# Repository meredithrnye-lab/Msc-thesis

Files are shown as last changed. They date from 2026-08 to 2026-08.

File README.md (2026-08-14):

# Design and Manufacturing Feasibility Assessment of a Hybrid Jamming Soft Robotic Finger Exoskeleton for Hand Rehabilitation
**This repository contains dissertation work completed in partial fulfillment of the requirements for the degree MSc Rehabilitation Engineering and Assistive Technologies of University College London**

[Dissertation Report](/Reports/Design%20and%20Manufacturing%20Feasibility%20Assessment%20of%20a%20Hybrid%20Jamming%20Soft%20Robotic%20Finger%20Exoskeleton%20for%20Hand%20Rehabilitation.pdf)
authored by [Meredith Nye](https://www.linkedin.com/in/meredith-nye-89455a1b5/), with advisors [Rui Loureiro](https://www.linkedin.com/in/rui-cv-loureiro/) and [Peter Kyberd](https://www.linkedin.com/in/peter-kyberd-b78b1757/)

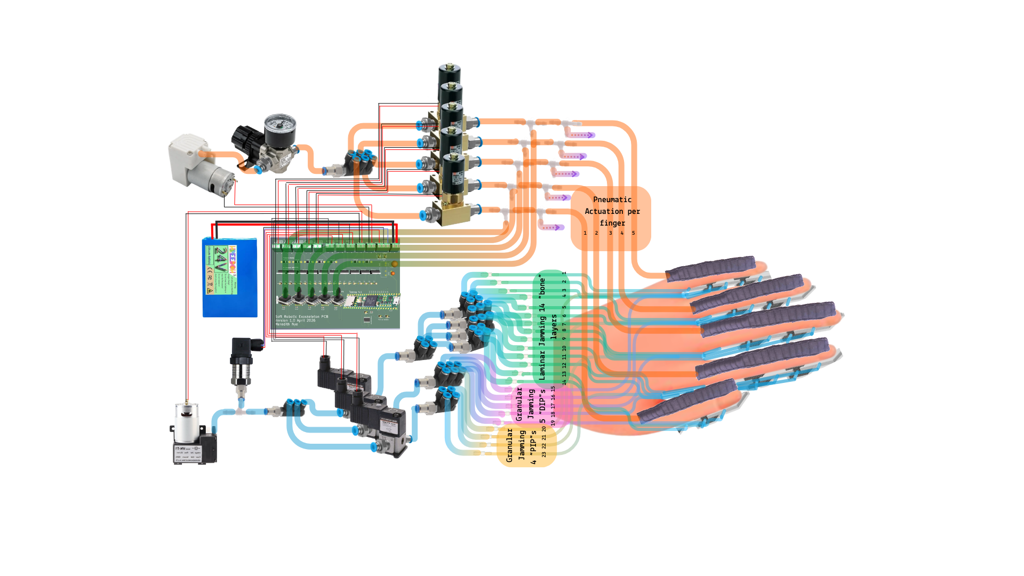
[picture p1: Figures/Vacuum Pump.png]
Full theoretical system design


## Abstract
#### Background and Aims 
Hand impairment 
following stroke, arthritis, and age-related conditions requires high-repetition rehabilitation
that soft robotic exoskeletons are well suited
to deliver. Jamming-based variable-stiffness
mechanisms are promising but underdeveloped, typically offering only single-family, binary stiffness control. This project aimed to
evaluate the design and manufacturing feasibility of a hybrid granular–laminar jamming
soft robotic finger exoskeleton, hypothesising
that hybrid jamming could be integrated into
a compact finger architecture without compromising manufacturability.

#### Methods 
Sixteen design specifications were synthesised from hand exoskeleton literature.
A finger-level prototype was partially built
comprising a fabric pneumatic actuator over
a silicone hybrid jamming module (adapted
from an existing H-block design), with custom PCB control. Actuators were manually
inflated; the jamming module was cast across
four silicone iterations. Each specification was
rated on design and manufacturing axes and
combined into an overall feasibility rating.

#### Results 
The jamming geometry was rated Feasible on the design axis, but all
four casting iterations showed persistent tackiness and incomplete curing at fine layer-pocket
features, so no complete module
was assembled. Fabric actuators inflated with
one demonstrating bending but did not reach
target flexion pressure. No inferential statistics
were applied; findings rest on single-prototype
demonstration and inspection evidence.

#### Summary and Conclusions 
The hybrid jamming specification was rated Not Feasible
overall, only partially supporting the hypothesis. Fine mold geometry and fabrication constraints, not conceptual incompatibility, prevented reliable manufacture. Hybrid jamming
remains a credible route to graduated-stiffness
rehabilitation exoskeletons, but reliable small scale silicone manufacturing must be resolved
before clinical translation.

## Relevant Repository Files
[PCB Gerber Files](/PCB%20Design/Gerbers.zip)

Version 3 Mold Files: [I3_RHM](/Manufacturing/V3_RM.stl), [I3_RHF](/Manufacturing/V3_RF.stl), [I3_LHM](/Manufacturing/V3_LM.stl), [I3_LHF](/Manufacturing/V3_LF.stl)

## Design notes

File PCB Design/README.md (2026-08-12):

# PCB Design
The custom PCB design is made to accommodate all the electronics needed for a
full glove system and uses a Teensy 4.1 micro-controller. It was manufactured by JLCPCB using an FR-4 substrate. 
Components were manually soldered to the board, with the 0805 surface-mount capacitors and TSSOP multiplexer soldered using a reflow process. 

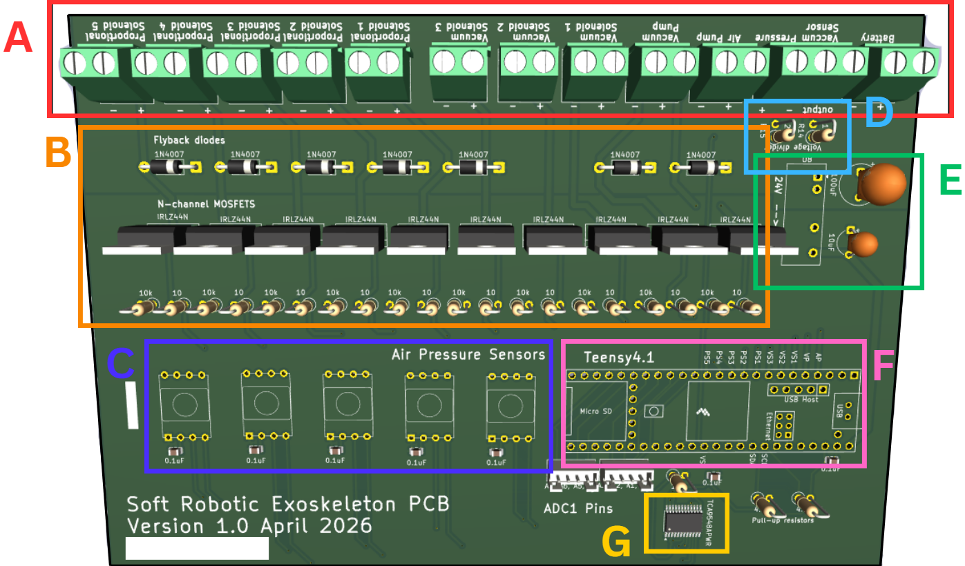
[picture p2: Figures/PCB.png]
PCB


This folder contains the KiCad files and gerber files associated with the first iteration of the PCB design.

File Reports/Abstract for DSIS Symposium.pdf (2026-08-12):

This project investigates a novel soft robotic exoskeleton design to enhance hand function in

individuals dealing with hand or finger muscle weakness. With a combined soft-fabric pneumatic

actuator and a bio-inspired granular-and-laminar jamming module, the soft exoskeleton aims to

achieve a biomimetic range of motion by varying the pneumatic actuator's air pressure across 8

distinct jamming configurations, with a similar or greater degree of stiffness modulation

compared to other designs. The pneumatic flexion will be achieved with an impulse-sealed air

pocket inside a pleated fabric pocket with stiff fabric lining the bottom layer, and elastic fabric

forming the top pleats. The jamming module will be silicone-molded following an H-block

design, in which rounded granular pockets serve as joints, and long laminar layers act as bones

slotted into the pockets to optimize load distribution along the exoskeleton's length. The study

will assess the feasibility of this design as a wearable exoskeleton, including overall device

weight, ROM, actuation speed, stiffness enhancement, and maximum force output, with and

without the jamming module. The aim is to contribute data on the viability and limits of jamming

mechanisms for enhancing soft robotic exoskeletons, as well as to provide insight into different

control methods that could optimize cost, computation speed, and functionality for soft robotic

exoskeletons.

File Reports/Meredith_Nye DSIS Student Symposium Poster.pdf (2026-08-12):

# Design and Evaluation of a Soft Exoskeleton Glove with Hybrid Jamming for Hand Rehabilitation

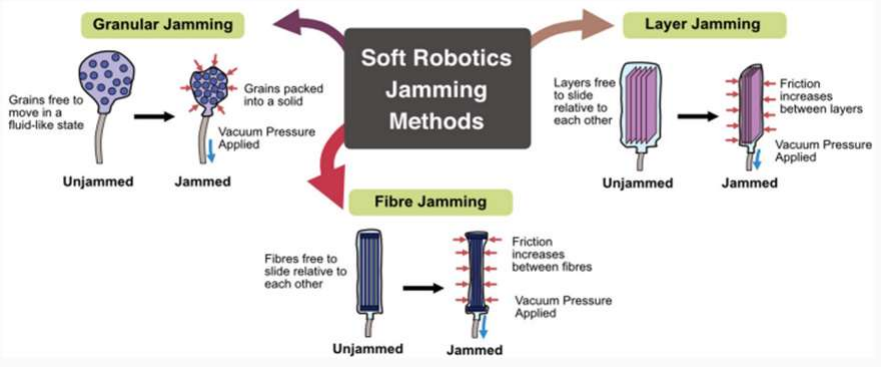
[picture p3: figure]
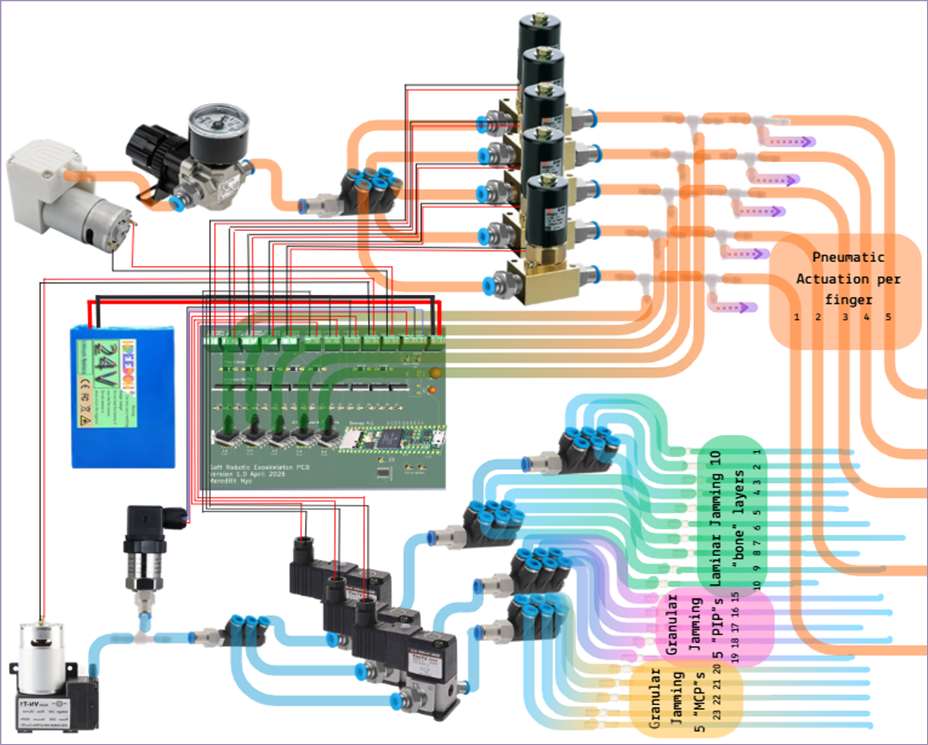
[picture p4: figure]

PRESENTER:
Program
Team
Supervisors

DSIS Student Research
Symposium 2026
PGT - 10

MSc Rehabilitation Eng. and Assistive Tech STARS Research Group
Rui Loureiro, Peter Kyberd

### Meredith Nye

Division of Surgery and Interventional Science, University College London

Figure adapted from: Liow L, Howard D. Jellyphant: A Soft, Elephant Trunk-Inspired Robotic Arm That Can Grab Objects. Frontiers for Young Minds. 2024.

# Background

Hand weakness resulting from neurological and musculoskeletal conditions can significantly impair daily function and quality of life. Effective rehabilitation often requires repetitive, progressive, and task-specific movement training with adaptable assistance (Reinkensmeyer et al., 2004). Soft robotic exoskeleton gloves have emerged as promising rehabilitation devices due to their flexibility, safety, and ability to support natural hand movement (Rus and Tolley, 2015). Jamming, shown below, is a technique used in soft robotics to provide controllable and reversible stiffness, allowing systems to remain flexible during movement while becoming rigid when additional support or stability is required.

# Aims

Aim:
To design and develop a bio-inspired soft exoskeleton glove incorporating hybrid jamming (granular and laminar) to provide adjustable, graduated support for hand rehabilitation. Research Questions:

### 1. Can a hybrid jamming structure provide

controllable and reversible stiffness and ROM suitable for assisting hand rehabilitation movements?

### 2. How does the design meet hand

rehabilitation requirements as determined from the literature?

### 3. How does the design compare quantitatively to

other designs in the research and on the market?

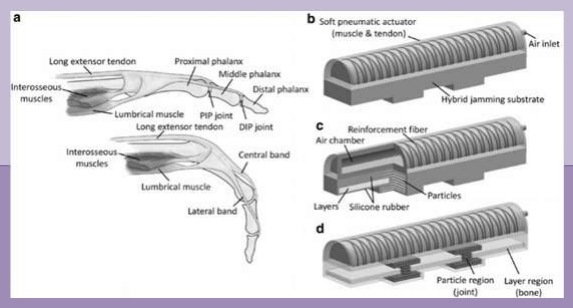
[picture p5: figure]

# Proposed Methodology

Testing will involve measuring force output and stiffness modulation with and without jamming, alongside ROM, actuation speed during finger flexion and extension, and power consumption. The goal is to provide a comprehensive look at the feasibility of the final design for hand rehabilitation.
Manufacturing will entail soldering custom PCB components, sewing, resin printing silicone molds, silicone pouring, and pneumatic pipe system construction.

# Design Rationale

Hand rehabilitation requires repetitive, task-specific movement with adjustable assistance, sufficient range of motion, and patient-specific adaptability. Devices must also be lightweight and safe to minimise user fatigue and reduce risk during prolonged use. The current design is also heavily inspired by pleated textile actuators and the bioinspired design shown below adopted from (Yang et al., 2019).

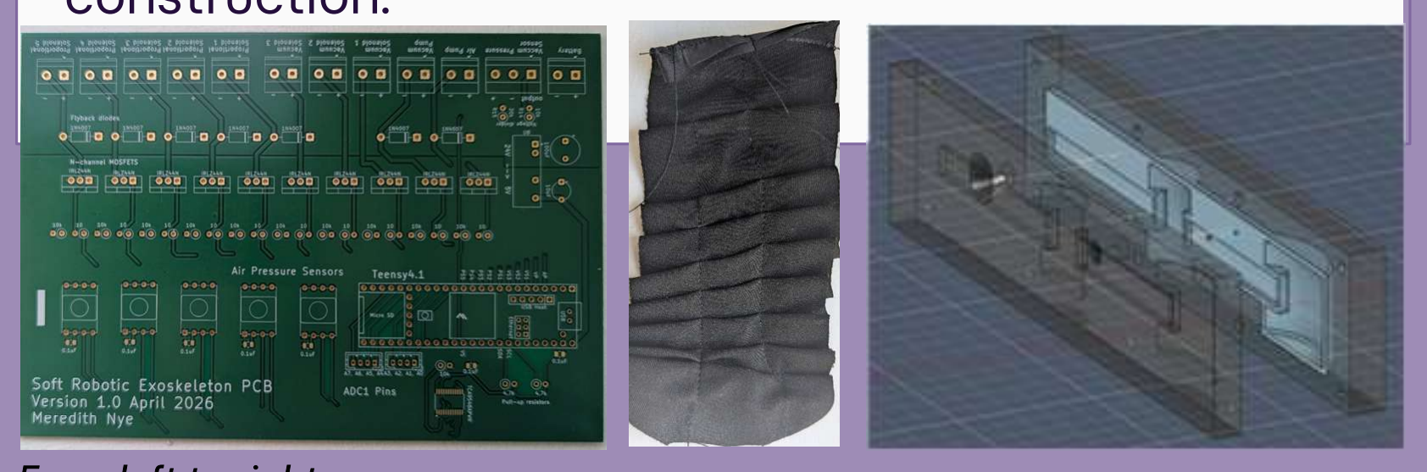
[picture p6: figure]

From left to right: Picture of the custom PCB board, hand-sewn fabric actuator mock-up, Fusion 360 model for the small half of the silicone finger’s resin mold A representation of the full glove design including battery, custom PCB with ground and power wirings, and tubing configurations where light blue tubes represent vacuum pressure and orange tubes represent air pressure.

Finger-level design of exoskeleton glove

The finger design has layered nylon fabric and mylar film for laminar jamming and EPS beads for granular jamming with oval silicone sections at the finger joints to improve fit and alignment targeting the higher load bearing joints as seen in the figure on the right.
A closed loop system will control the air pump-fabric actuator system, while the vacuum pump-jamming system will remain open loop within 8 different jamming configurations.

Reinkensmeyer, D.J. et al. (2004) Robotics in rehabilitation: A review of upper limb motor recovery after stroke. Rus, D. and Tolley, M.T. (2015) Design, fabrication and control of soft robots.

Yang, Y., Zhang, Y., Kan, Z., Zeng, J. and Wang, M.Y. (2019) Hybrid jamming for bioinspired soft robotic fingers. Soft Robotics. doi:10.1089/soro.2018.0101
Liow, L. and Howard, D. (2024) Jellyphant: A soft, elephant trunk-inspired robotic arm that can grab objects. Frontiers for Young Minds, 12:1341887. doi:10.3389/frym.2024.1341887

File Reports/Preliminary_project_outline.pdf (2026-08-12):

# A soft exoskeleton with hybridjamming towards hand rehabilitation

Meredith Nye

## Introduction

- Hand rehabilitation often requires repetitive, progressive, and variable movements with adjustable assistance (Reinkensmeyer et al., 2004).
- Soft exoskeleton gloves can provide clinical hand rehabilitation support (Rus and Tolley, 2015).
- This thesis aims to design, create, and test a bio-inspired, hybridjamming soft exoskeleton design that prioritizes graduated support and unique control for personalized rehabilitation.
- Hybrid jamming is the combination of granular jamming and laminar jamming. These refer to phenomena in which granular material or layers, respectively, placed in a flexible non-porous membrane can reversibly transition from a low stiffness state to a high stiffness state by applying a vacuum pressure.
David J. Reinkensmeyer et al. (2004). Robotic guidance and assistance as needed in neurorehabilitation. Advanced Robotics, 18(7), 695–715.
Daniela Rus & Michael T. Tolley (2015). Design, fabrication and control of soft robots. Nature, 521(7553), 467–475. https://doi.org/10.1038/nature14543

## Finger-level design

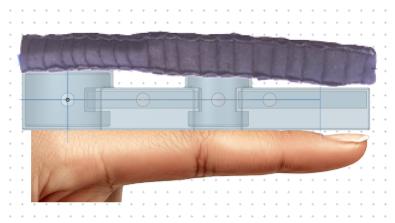
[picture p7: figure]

- Pneumatic Fabric Actuator
- Air-pressure determines bending force
- Hybrid Jamming Bio-Inspired Design
- Granular jamming pockets act as joints (targeting MCP and DIP), laminar jamming pockets act as bones

## Testing and Outcomes

- Will assess the feasibility of the design as a wearable exoskeleton, including overall device weight, ROM, actuation speed, stiffness enhancement, and maximum force output, with and without the jamming.
- The aim is to contribute data on the viability and limits of jamming mechanisms for enhancing soft robotic exoskeletons in the context of hand rehabilitation, as well as to provide insight into different control methods that could optimize cost, computation speed, and functionality for soft robotic exoskeletons.

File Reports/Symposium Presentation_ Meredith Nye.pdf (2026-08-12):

# Design and Evaluation of a Soft Exoskeleton Finger with Hybrid Jamming towards Hand Rehabilitation

Meredith Nye, advised by Rui Loureiro 16 July 2026

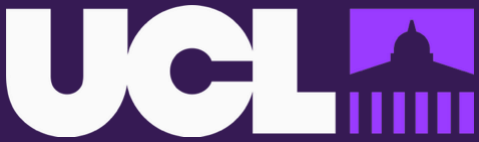
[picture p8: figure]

SURG0095, Division of Surgery and Interventional Science

## Context

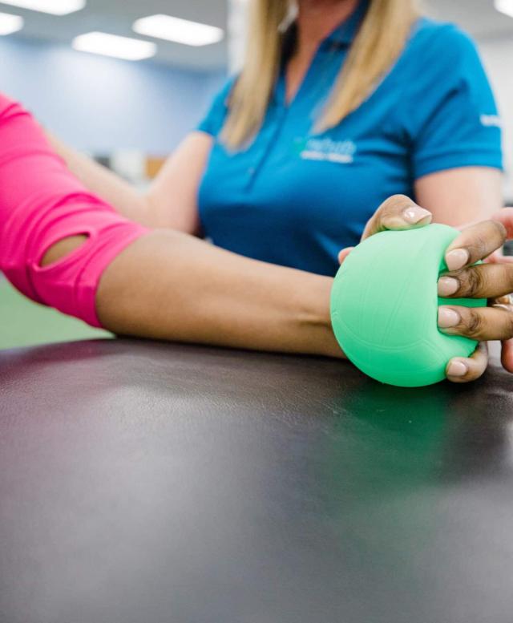
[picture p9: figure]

- Everyone in this room is getting older.
- 1 in 4 people above the age of 25 will experience a stroke in their lifetime. (Feigin et al., 2025)
- Less than 20% will regain full upper limb
function. (Graham, 2024)
- We all rely heavily on our hands for daily activities
(Graham, 2024)

## Context

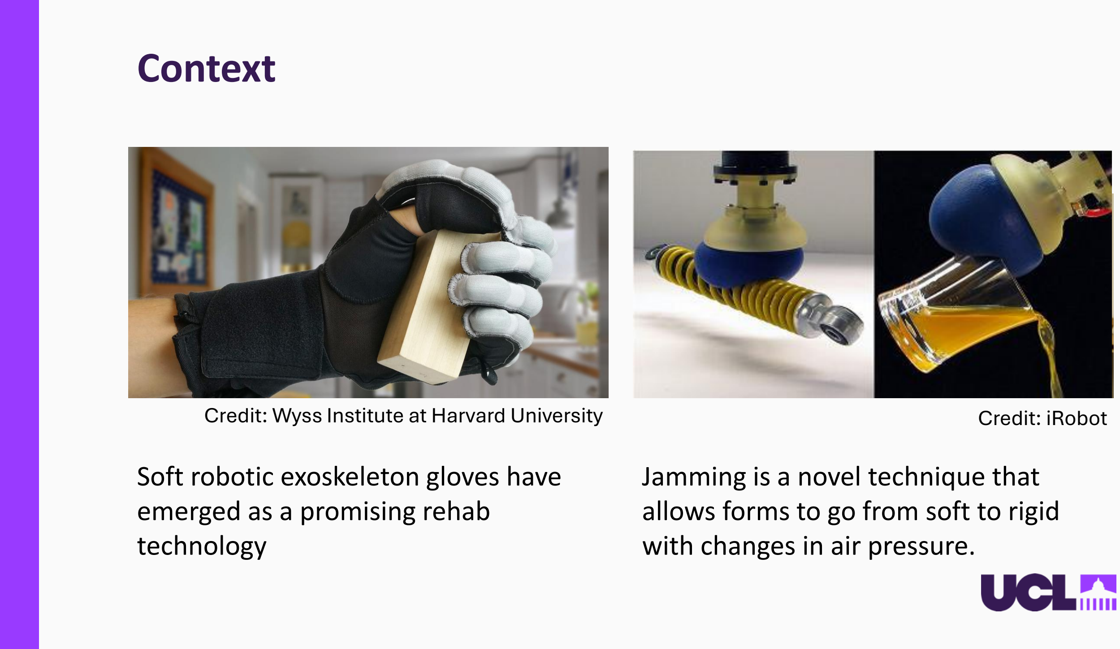
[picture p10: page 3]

Soft robotic exoskeleton gloves have emerged as a promising rehab technology

Jamming is a novel technique that allows forms to go from soft to rigid with changes in air pressure.

Credit: Wyss Institute at Harvard University | Credit: iRobot

## My design

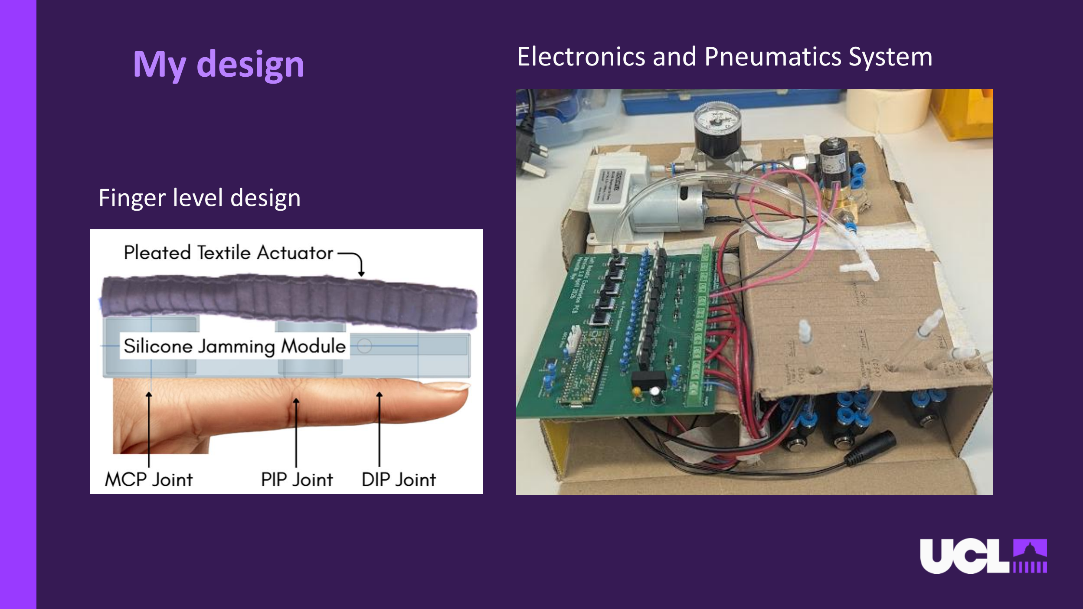
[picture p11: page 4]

Finger level design

Electronics and Pneumatics System

## Design Aims- Lab based project

Investigate a soft exoskeleton finger design using granular and laminar jamming.

- Can hybrid jamming provide new exoskeleton characteristics?
- How does the finger meet rehabilitation requirements?
- How does the finger compare to other designs?

## Manufacturing and Methods

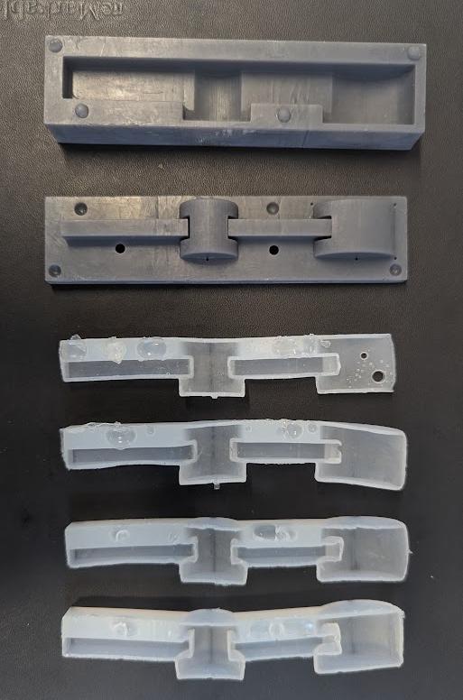
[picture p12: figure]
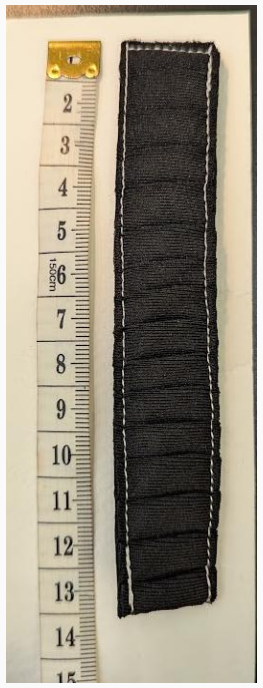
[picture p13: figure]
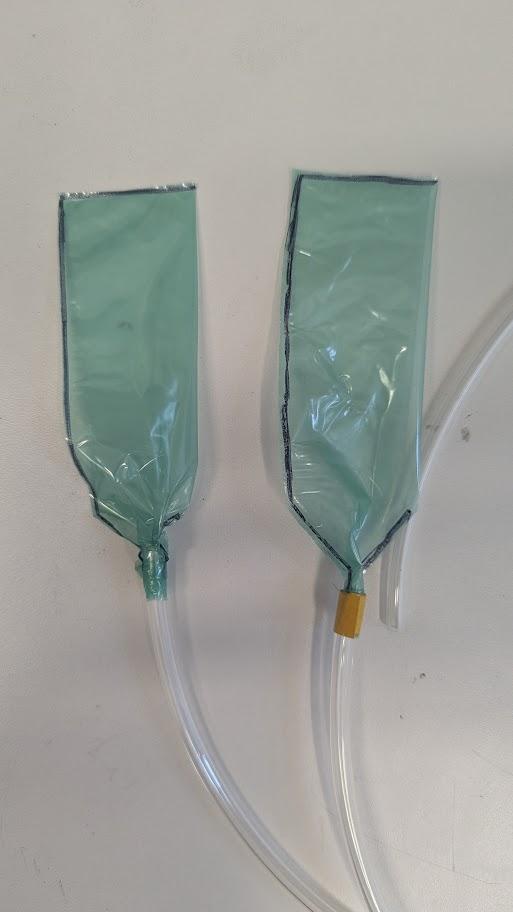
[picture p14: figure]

Prototype testing:
- Measuring force
output at the finger’s tip
- Measuring stiffness
modulation
- Actuation speed
- Power consumption

## Outcomes

Expected results:
- Joint level range of motion achievement while different jamming pockets are activated
- Force output within the 8 - 9N range
- 5 -10x stiffness variation

Takeaways so far:
- The manufacturing process is a bottleneck for the finger design.
- Novel system complexity adds cost, weight, and manufacturing time.

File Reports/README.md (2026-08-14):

# Reports and Presentations

This folder contains the final thesis report and relevant presentations given throughout the process of the dissertation. This includes the 
project Viva presentation.

### [Dissertation Report](Design%20and%20Manufacturing%20Feasibility%20Assessment%20of%20a%20Hybrid%20Jamming%20Soft%20Robotic%20Finger%20Exoskeleton%20for%20Hand%20Rehabilitation.pdf)
- This is the dissertation report turned in August 2026 as part of the requirements for the MSc degree and dissertation course.
### [Preliminary Project Outline](Preliminary_project_outline.pdf)
- This PowerPoint was made early in the dissertation process for advisors to review and offer comments on the overall scope of the work you plan to do.
### [DSIS Symposium Poster](Meredith_Nye%20DSIS%20Student%20Symposium%20Poster.pdf)
- The poster presented at the Division of Surgery and Interventional Science's Annual Research Symposium. Prior to the symposium a [preliminary abstract](Abstract%20for%20DSIS%20Symposium.pdf) was submitted to the division. This was an optional, unmarked symposium.  
### [Department Symposium Presentation](Symposium%20Presentation_%20Meredith%20Nye.pdf)
- This PowerPoint was made for the department's mandatory research symposium. Student's were given 5 minutes to cover the scope of their work so far and plans for completion, followed by 10 minutes of questions. This presentation was unmarked but beneficial for Viva prep. 
### [Viva Presentation](Final_Viva_Presentation.pdf)
- This PowerPoint is the presentation used for the online thesis defense given as partial fulfillment of the requirements for the MSc degree and dissertation course. The viva consisted of the 3 minute presentation and approx. 22 minutes of questions.

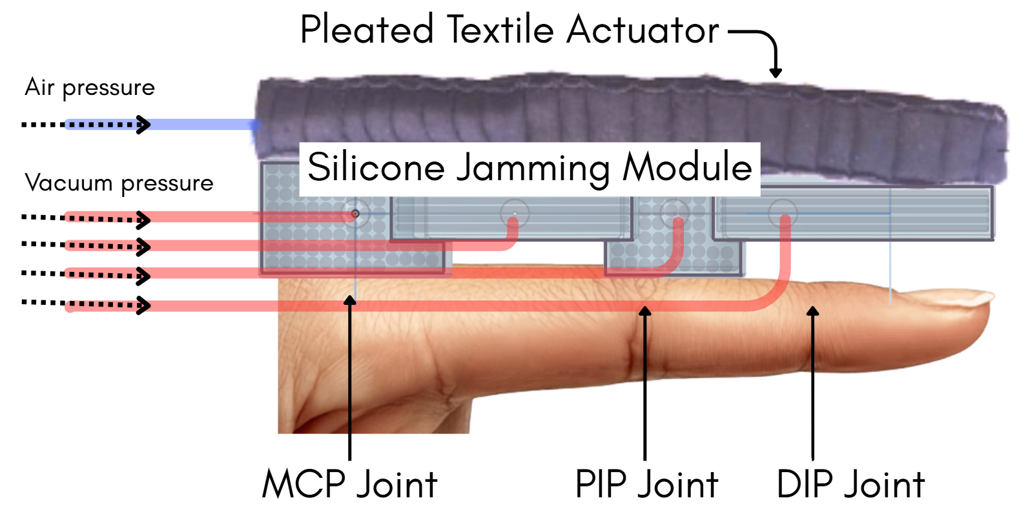
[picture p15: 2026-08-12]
Figures/fingerleveldesign.png

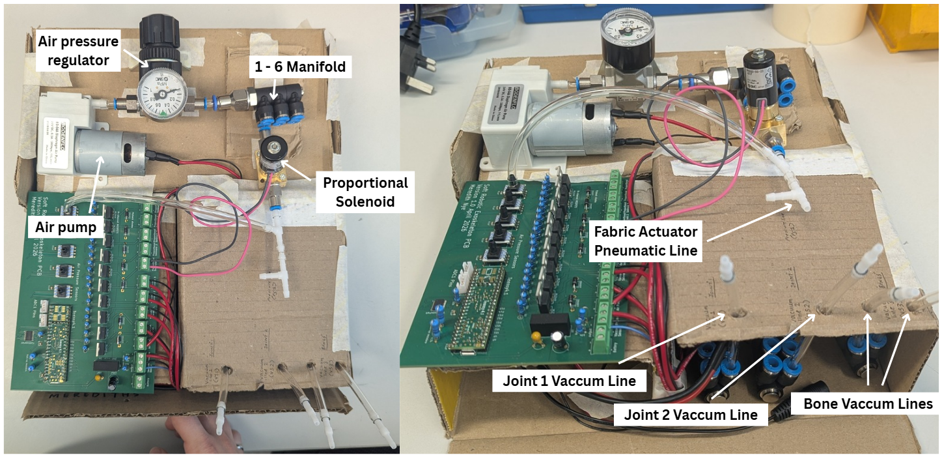
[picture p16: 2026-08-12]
Figures/Physical_hardware.png

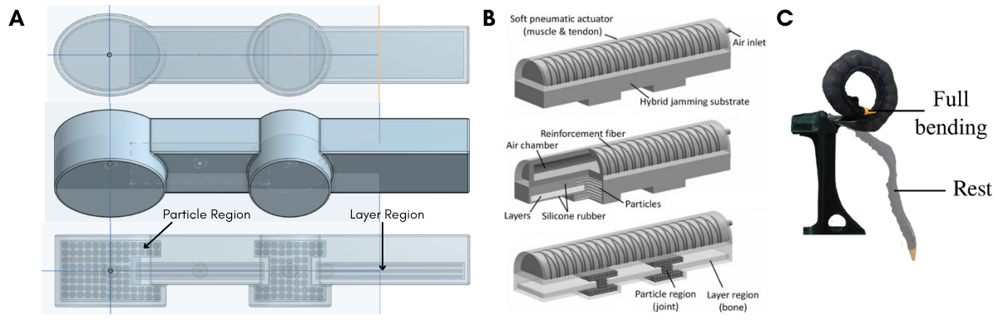
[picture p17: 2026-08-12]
Figures/Finger module and comparisons.png

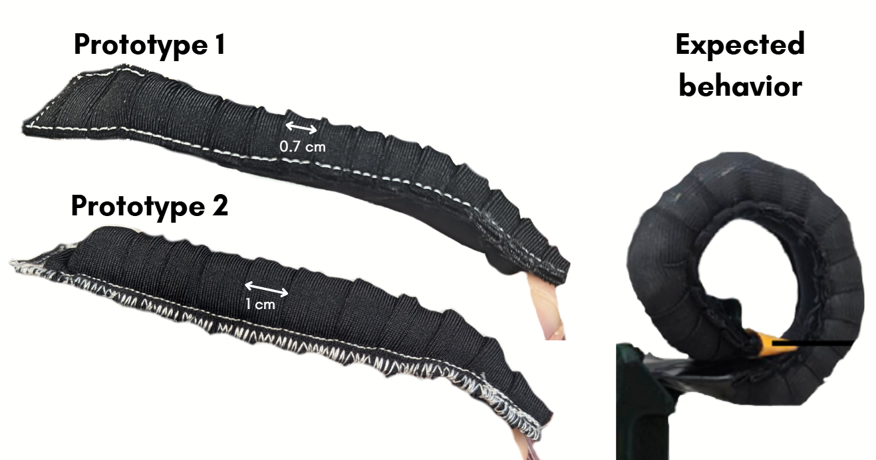
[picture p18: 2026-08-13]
Figures/inflatedactuators.png

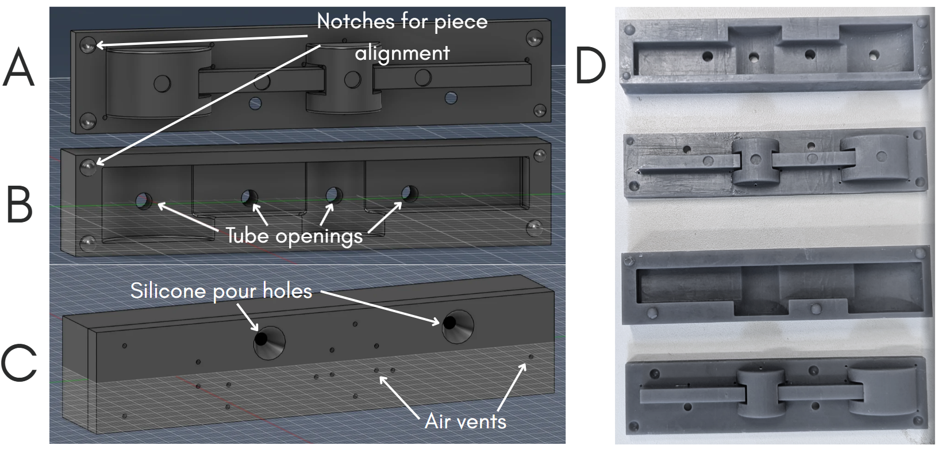
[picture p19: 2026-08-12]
Figures/moldmodels.png

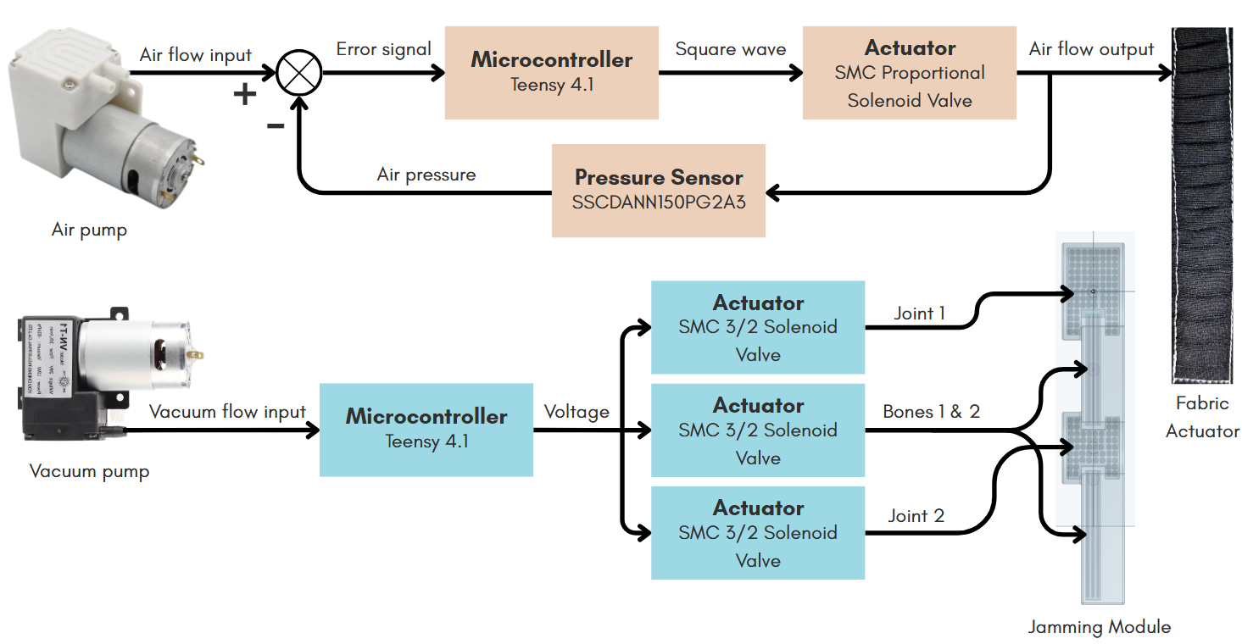
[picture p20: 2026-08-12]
Figures/controldiagram.png

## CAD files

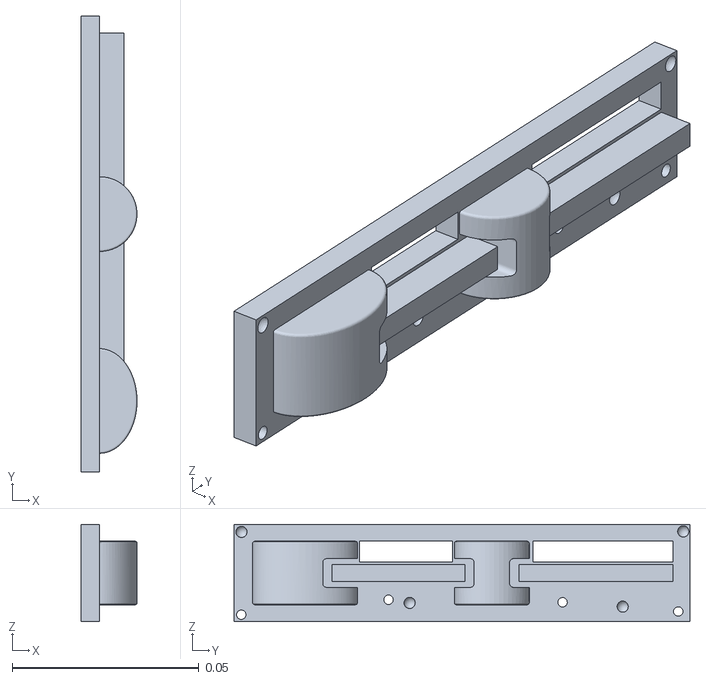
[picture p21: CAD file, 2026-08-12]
Manufacturing/V3_LM.stl
0.015 x 0.122 x 0.026

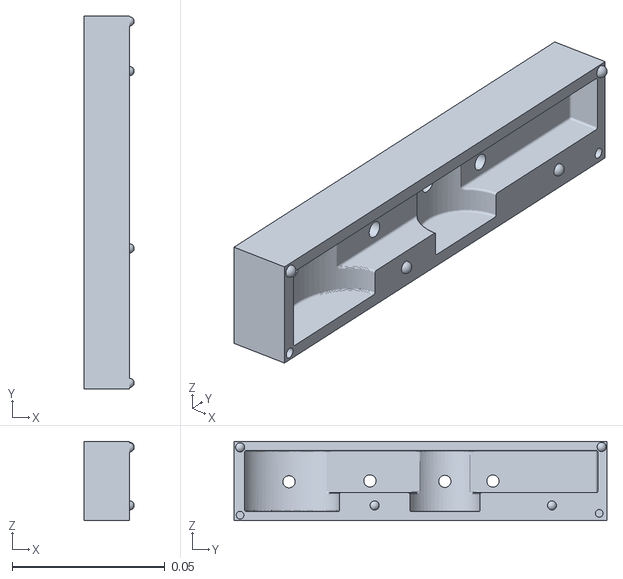
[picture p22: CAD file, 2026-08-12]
Manufacturing/V3_RF.stl
0.0165 x 0.122 x 0.026

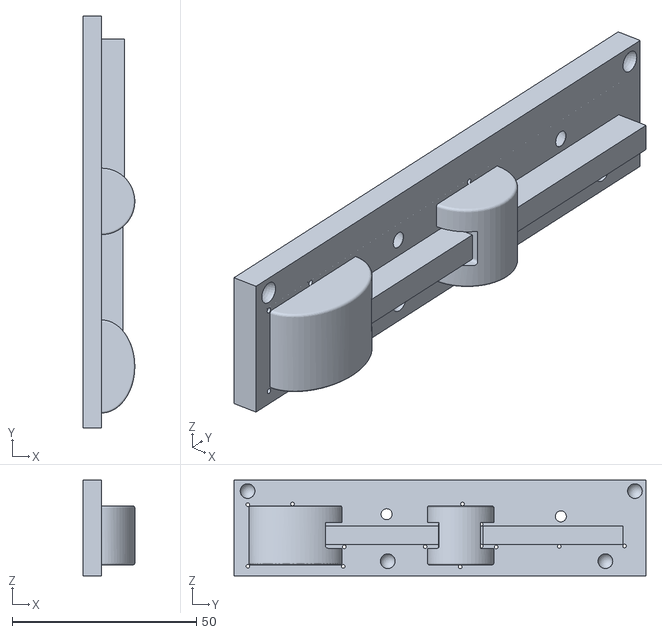
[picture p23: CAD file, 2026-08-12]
Manufacturing/right half finger_male mold piece.stl
14.0 x 111.7 x 26.0

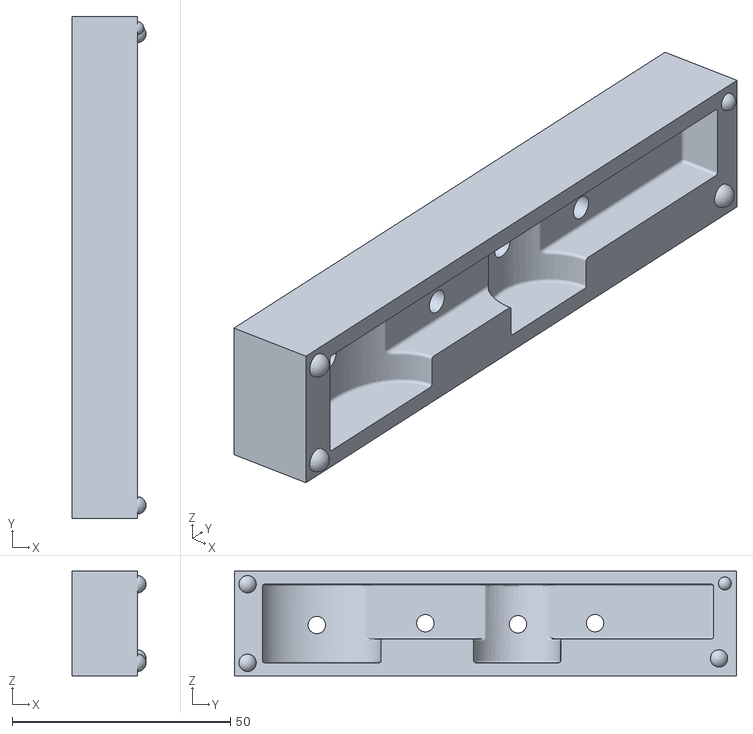
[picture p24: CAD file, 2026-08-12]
Manufacturing/left half finger_ female mold piece.stl
17.0 x 115.0 x 24.0

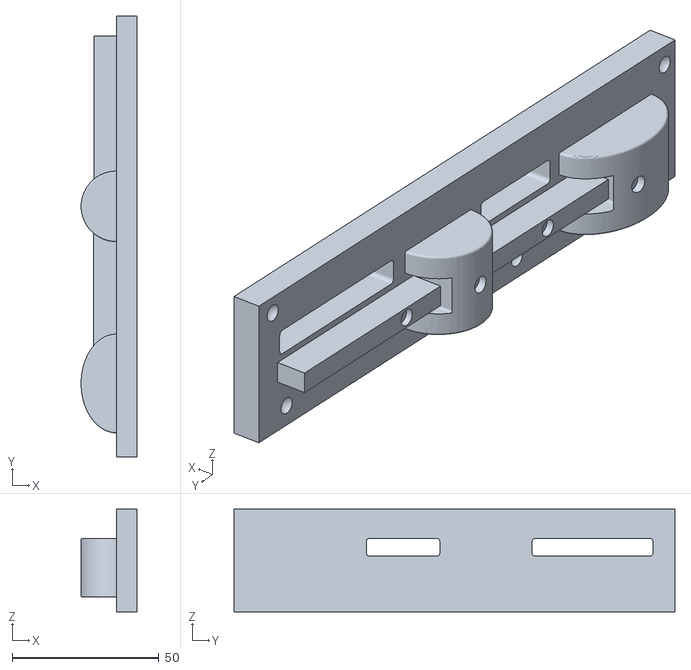
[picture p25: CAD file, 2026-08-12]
Manufacturing/Iteration2_right_male_mold.stl
19.0 x 150.0 x 35.0

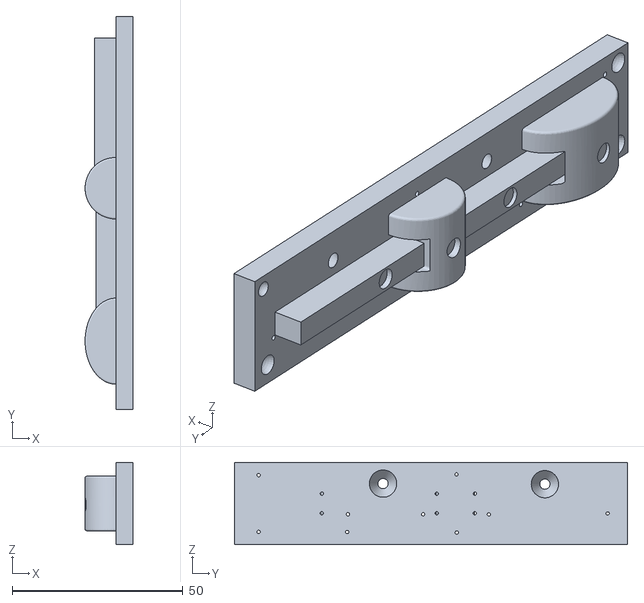
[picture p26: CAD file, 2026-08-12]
Manufacturing/left half finger_male mold piece.stl
14.0 x 115.0 x 24.0

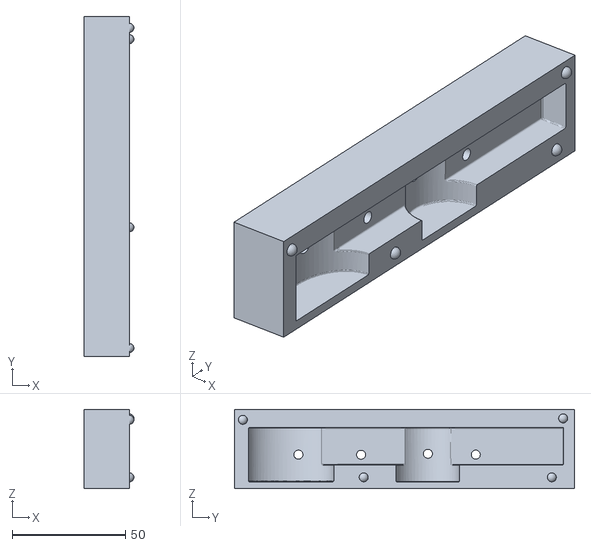
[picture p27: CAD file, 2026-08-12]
Manufacturing/Iteration2_right_female_mold.stl
22.0 x 150.0 x 35.0

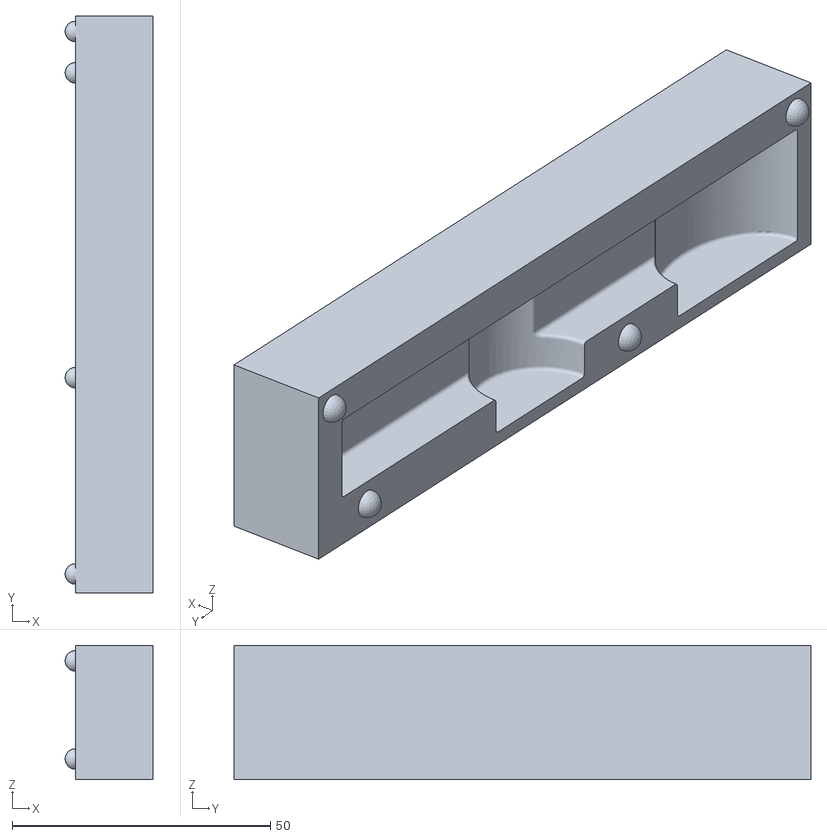
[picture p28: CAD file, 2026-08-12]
Manufacturing/right half finger_female mold piece.stl
17.0 x 111.7 x 26.0

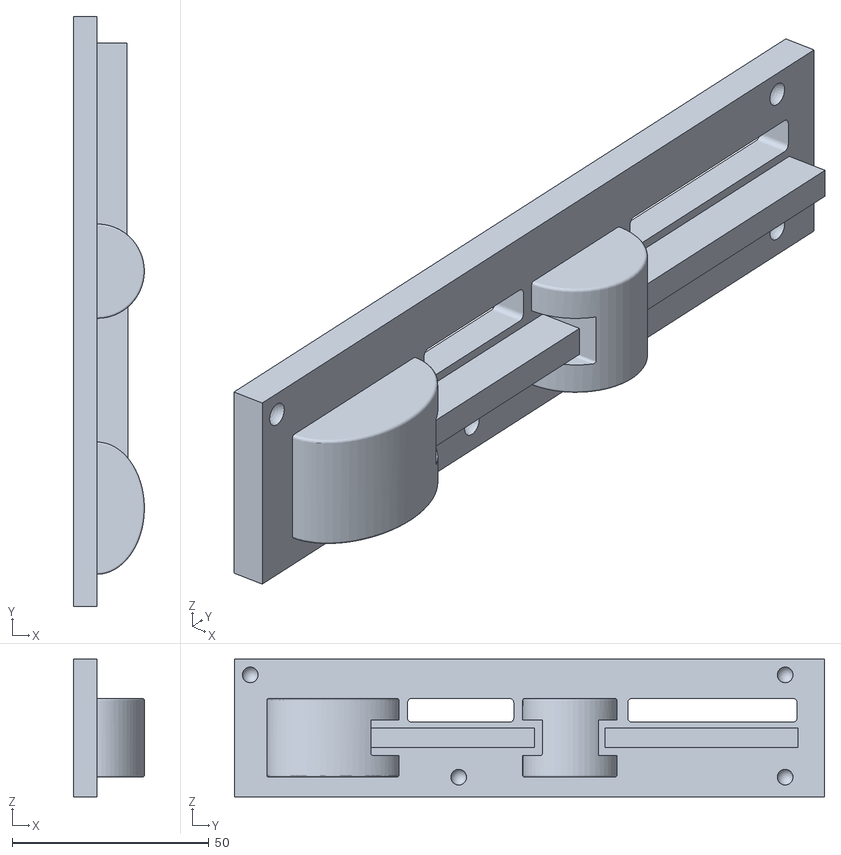
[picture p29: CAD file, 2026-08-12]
Manufacturing/Iteration2_left_male_mold.stl
18.0 x 150.0 x 35.0

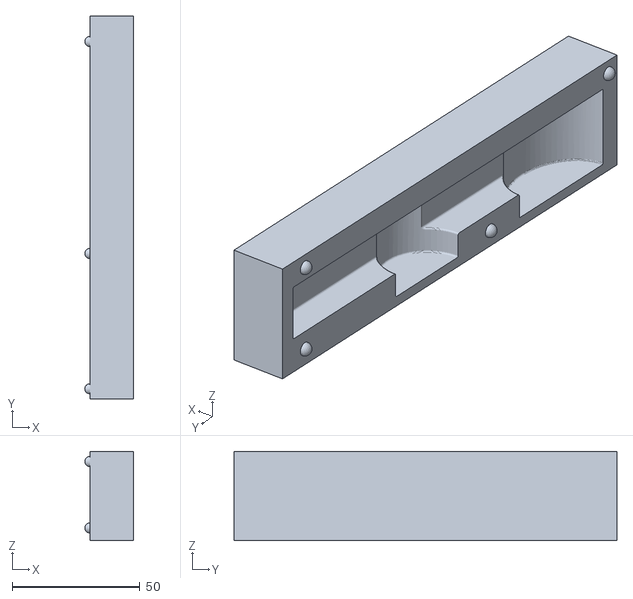
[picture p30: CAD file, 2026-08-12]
Manufacturing/Iteration2_left_female_mold.stl
19.0 x 150.0 x 35.0

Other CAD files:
Manufacturing/V3_RM.stl
Manufacturing/V3_LF.stl

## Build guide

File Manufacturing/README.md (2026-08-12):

# Manufacturing 
This folder contains relevant files to the manufacturing process of the soft robotic exoskeleton prototype. 

## Mold Designs
The full prototype requires 4 different mold pieces: 2 for each half of the finger. Each half has a female part and a male part. The naming convention is therefore 

- IX_RHM = Iteration x, Right half male
- IX_RHF = Iteration x, Right half female
- IX_LHM = Iteration x, Left half male
- IX_LHF = Iteration x, Left half female

[I1_RHM](right%20half%20finger_male%20mold%20piece.stl), [I1_RHF](right%20half%20finger_female%20mold%20piece.stl), [I1_LHM](left%20half%20finger_male%20mold%20piece.stl), [I1_LHF](left%20half%20finger_%20female%20mold%20piece.stl)

[I2_RHM](Iteration2_right_male_mold.stl), [I2_RHF](Iteration2_right_male_femold.stl), [I2_LHM](Iteration2_left_male_mold.stl), [I2_LHF](Iteration2_left_female_mold.stl)

[I3_RHM](V3_RM.stl), [I3_RHF](V3_RF.stl), [I3_LHM](V3_LM.stl), [I3_LHF](V3_LF.stl)

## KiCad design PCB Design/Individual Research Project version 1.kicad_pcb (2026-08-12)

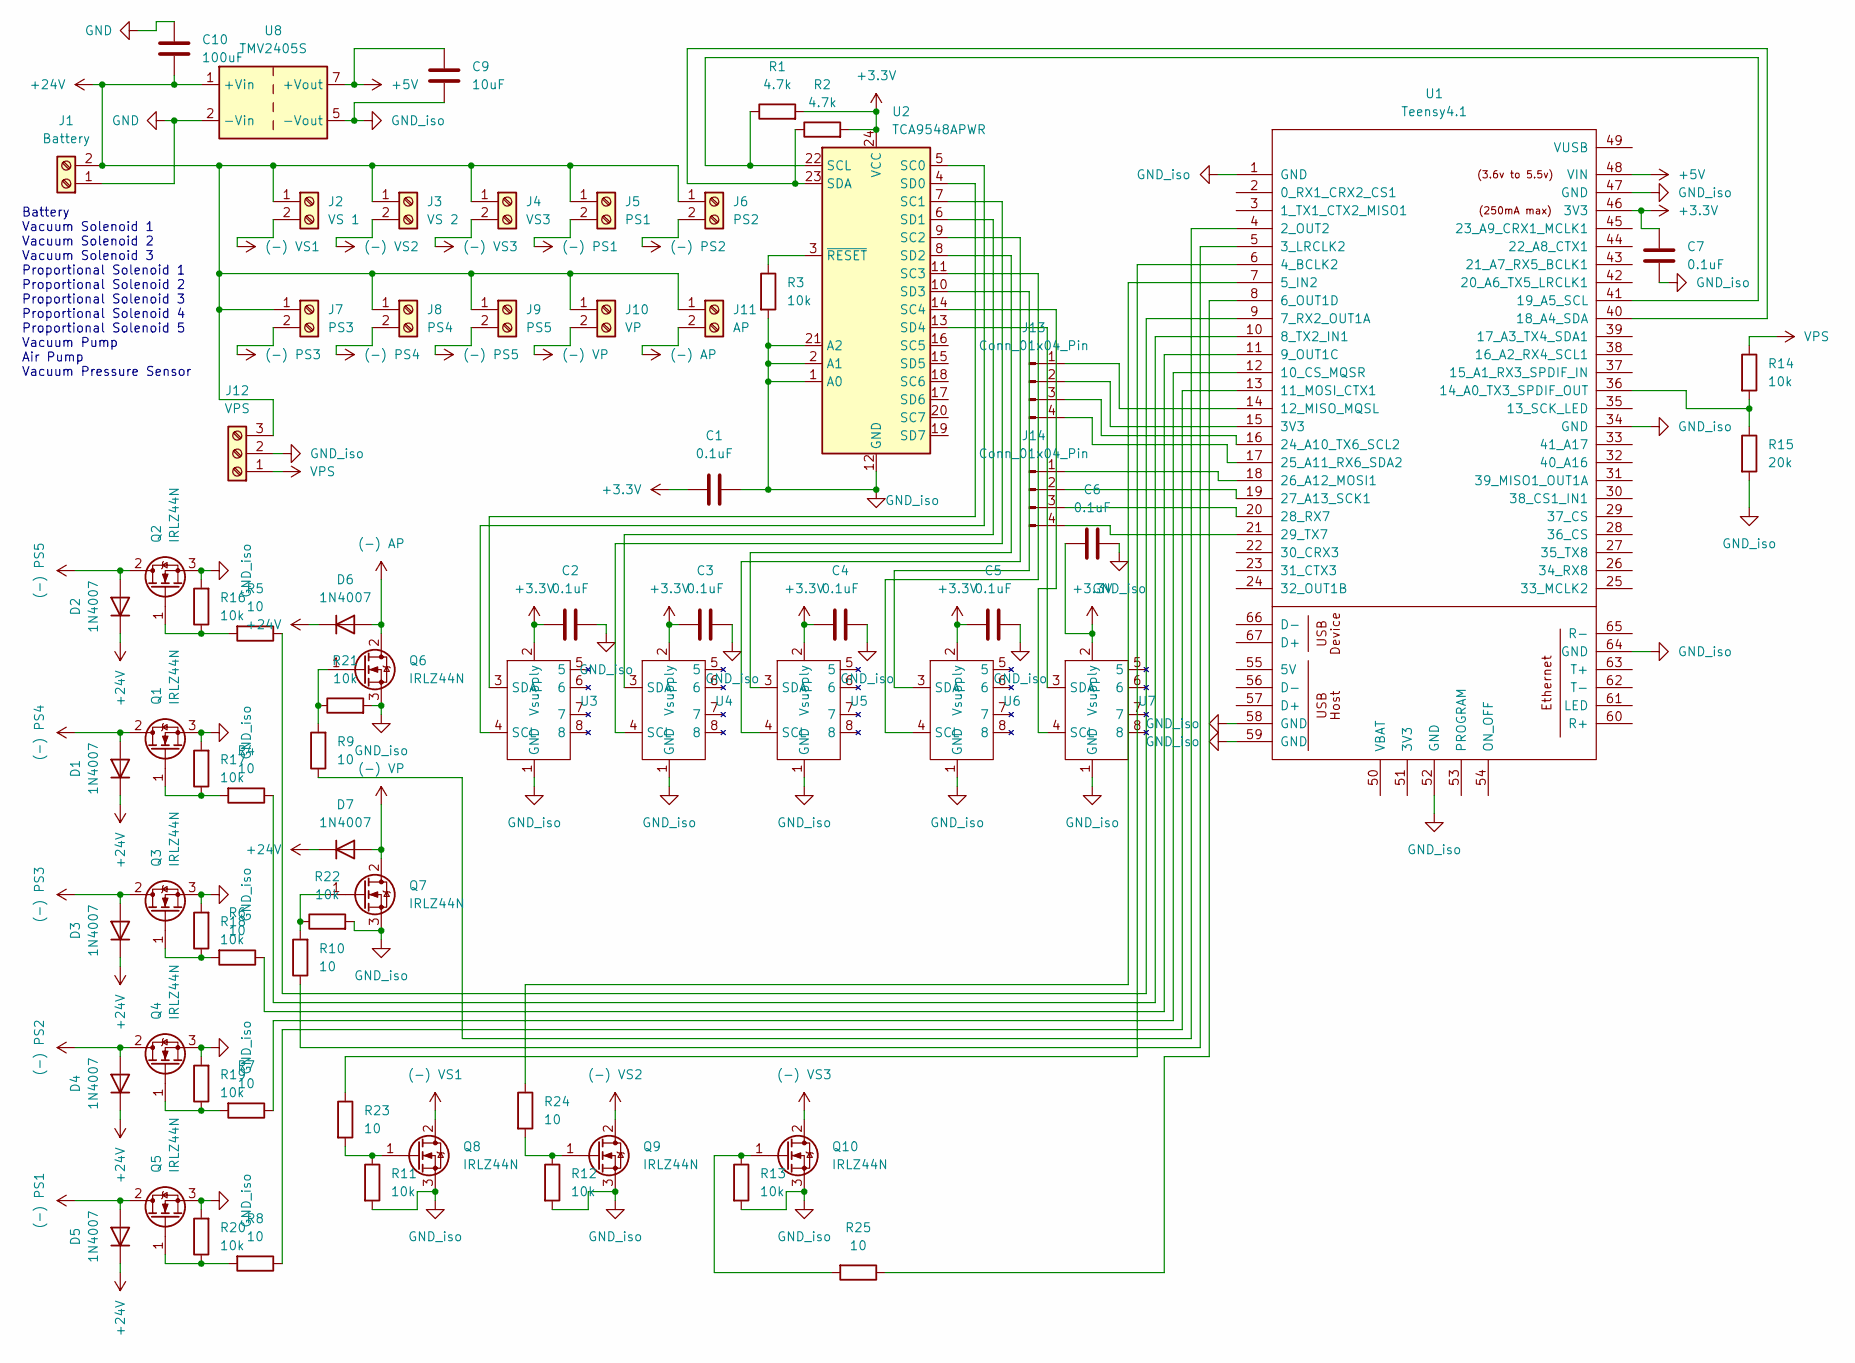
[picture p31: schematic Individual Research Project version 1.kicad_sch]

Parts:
C1, C2, C3, C4, C5, C6, C7: 0.1uF; C_0805_2012Metric
C9: 10uF; CP_Radial_Tantal_D5.0mm_P5.00mm
C10: 100uF; CP_Radial_Tantal_D8.0mm_P5.00mm
D1, D2, D3, D4, D5, D6, D7: 1N4007; D_DO-41_SOD81_P10.16mm_Horizontal
J1: Battery; TerminalBlock_Phoenix_MKDS-1,5-2-5.08_1x02_P5.08mm_Horizont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
J2: VS 1; TerminalBlock_Phoenix_MKDS-1,5-2-5.08_1x02_P5.08mm_Horizont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
J3: VS 2; TerminalBlock_Phoenix_MKDS-1,5-2-5.08_1x02_P5.08mm_Horizont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
J4: VS3; TerminalBlock_Phoenix_MKDS-1,5-2-5.08_1x02_P5.08mm_Horizont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
J5: PS1; TerminalBlock_Phoenix_MKDS-1,5-2-5.08_1x02_P5.08mm_Horizont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
J6: PS2; TerminalBlock_Phoenix_MKDS-1,5-2-5.08_1x02_P5.08mm_Horizont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
J7: PS3; TerminalBlock_Phoenix_MKDS-1,5-2-5.08_1x02_P5.08mm_Horizont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
J8: PS4; TerminalBlock_Phoenix_MKDS-1,5-2-5.08_1x02_P5.08mm_Horizont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
J9: PS5; TerminalBlock_Phoenix_MKDS-1,5-2-5.08_1x02_P5.08mm_Horizont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
J10: VP; TerminalBlock_Phoenix_MKDS-1,5-2-5.08_1x02_P5.08mm_Horizont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
J11: AP; TerminalBlock_Phoenix_MKDS-1,5-2-5.08_1x02_P5.08mm_Horizont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
J12: VPS; TerminalBlock_Phoenix_MKDS-1,5-3-5.08_1x03_P5.08mm_Horizont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
J13, J14: Conn_01x04_Pin; JST_PH_B4B-PH-K_1x04_P2.00mm_Vertical
Q1, Q2, Q3, Q4, Q5, Q6, Q7, Q8, Q9, Q10: IRLZ44N; TO-220-3_Vertical
R1, R2: 4.7k; R_Axial_DIN0207_L6.3mm_D2.5mm_P2.54mm_Vertical
R3, R11, R12, R13, R14, R16, R17, R18, R19, R20, R21, R22: 10k; R_Axial_DIN0207_L6.3mm_D2.5mm_P2.54mm_Vertical
R4, R5, R6, R7, R8, R9, R10, R23, R24, R25: 10; R_Axial_DIN0207_L6.3mm_D2.5mm_P2.54mm_Vertical
R15: 20k; R_Axial_DIN0207_L6.3mm_D2.5mm_P2.54mm_Vertical
U1: Teensy4.1; Teensy41
U2: TCA9548APWR; TSSOP-24_4.4x7.8mm_P0.65mm
U3, U4, U5, U6, U7: SSCDANN; SSCAN
U8: TMV2405S; Converter_DCDC_TRACO_TMV-241xS_Single_THT

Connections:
(-) AP: D6.2 (A), J11.2, Q6.2 (D)
(-) PS1: D5.2 (A), J5.2, Q5.2 (D)
(-) PS2: D4.2 (A), J6.2, Q4.2 (D)
(-) PS3: D3.2 (A), J7.2, Q3.2 (D)
(-) PS4: D1.2 (A), J8.2, Q1.2 (D)
(-) PS5: D2.2 (A), J9.2, Q2.2 (D)
(-) VP: D7.2 (A), J10.2, Q7.2 (D)
(-) VS1: J2.2, Q8.2 (D)
(-) VS2: J3.2, Q9.2 (D)
(-) VS3: J4.2, Q10.2 (D)
+3.3V: C1.1, C2.1, C3.1, C4.1, C5.1, C6.1, C7.2, R1.2, R2.2, U1.46 (3V3), U2.24 (VCC), U3.2 (Vsupply), U4.2 (Vsupply), U5.2 (Vsupply), U6.2 (Vsupply), U7.2 (Vsupply)
+5V: C9.2, U1.48 (VIN), U8.7 (+Vout)
+24V: C10.1, D1.1 (K), D2.1 (K), D3.1 (K), D4.1 (K), D5.1 (K), D6.1 (K), D7.1 (K), J1.2, J2.1, J3.1, J4.1, J5.1, J6.1, J7.1, J8.1, J9.1, J10.1, J11.1, J12.3, U8.1 (+Vin)
GND: C10.2, J1.1, U8.2 (-Vin)
GND_iso: C1.2, C2.2, C3.2, C4.2, C5.2, C6.2, C7.1, C9.1, J12.2, Q1.3 (S), Q2.3 (S), Q3.3 (S), Q4.3 (S), Q5.3 (S), Q6.3 (S), Q7.3 (S), Q8.3 (S), Q9.3 (S), Q10.3 (S), R3.2, R11.2, R12.2, R13.2, R15.2, R16.2, R17.2, R18.2, R19.2, R20.2, R21.2, R22.2, U1.1 (GND), U1.34 (GND), U1.47 (GND), U1.52 (GND), U1.58 (GND), U1.59 (GND), U1.64 (GND), U2.1 (A0), U2.2 (A1), U2.12 (GND), U2.21 (A2), U3.1 (GND), U4.1 (GND), U5.1 (GND), U6.1 (GND), U7.1 (GND), U8.5 (-Vout)
unnamed 15: J13.1, U1.14 (12_MISO_MQSL); also elsewhere on the board
unnamed 16: J13.2, U1.15 (3V3); also elsewhere on the board
unnamed 17: J13.3, U1.16 (24_A10_TX6_SCL2); also elsewhere on the board
unnamed 18: J13.4, U1.17 (25_A11_RX6_SDA2); also elsewhere on the board
unnamed 19: J14.1, U1.18 (26_A12_MOSI1); also elsewhere on the board
unnamed 20: J14.2, U1.19 (27_A13_SCK1); also elsewhere on the board
unnamed 21: J14.3, U1.20 (28_RX7); also elsewhere on the board
unnamed 22: J14.4, U1.21 (29_TX7); also elsewhere on the board
unnamed: Q1.1 (G), R4.2, R17.1
unnamed: Q2.1 (G), R5.2, R16.1
unnamed: Q3.1 (G), R6.2, R18.1
unnamed: Q4.1 (G), R7.2, R19.1
unnamed: Q5.1 (G), R8.2, R20.1
unnamed: Q6.1 (G), R9.2, R21.1
unnamed: Q7.1 (G), R10.2, R22.1
unnamed: Q8.1 (G), R11.1, R23.2
unnamed: Q9.1 (G), R12.1, R24.2
unnamed: Q10.1 (G), R13.1, R25.2
unnamed: R9.1, U1.4 (2_OUT2)
unnamed: R10.1, U1.5 (3_LRCLK2)
unnamed: R23.1, U1.6 (4_BCLK2)
unnamed: R24.1, U1.7 (5_IN2)
unnamed: R25.1, U1.8 (6_OUT1D)
unnamed: R5.1, U1.9 (7_RX2_OUT1A)
unnamed: R4.1, U1.10 (8_TX2_IN1)
unnamed: R6.1, U1.11 (9_OUT1C)
unnamed: R7.1, U1.12 (10_CS_MQSR)
unnamed: R8.1, U1.13 (11_MOSI_CTX1)
unnamed: R14.2, R15.1, U1.36 (14_A0_TX3_SPDIF_OUT)
unnamed: R2.1, U1.40 (18_A4_SDA), U2.23 (SDA)
unnamed: R1.1, U1.41 (19_A5_SCL), U2.22 (SCL)
unnamed: U2.5 (SC0), U3.4 (SCL)
unnamed: U2.7 (SC1), U4.4 (SCL)
unnamed: U2.9 (SC2), U5.4 (SCL)
unnamed: U2.11 (SC3), U6.4 (SCL)
unnamed: U2.14 (SC4), U7.4 (SCL)
unnamed: U2.4 (SD0), U3.3 (SDA)
unnamed: U2.6 (SD1), U4.3 (SDA)
unnamed: U2.8 (SD2), U5.3 (SDA)
unnamed: U2.10 (SD3), U6.3 (SDA)
unnamed: U2.13 (SD4), U7.3 (SDA)
unnamed: R3.1, U2.3 (~RESET)
VPS: J12.1, R14.1

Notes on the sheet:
Battery Vacuum Solenoid 1 Vacuum Solenoid 2 Vacuum Solenoid 3 Proportional Solenoid 1 Proportional Solenoid 2 Proportional Solenoid 3 Proportional Solenoid 4 Proportional Solenoid 5 Vacuum Pump Air Pump Vacuum Pressure Sensor

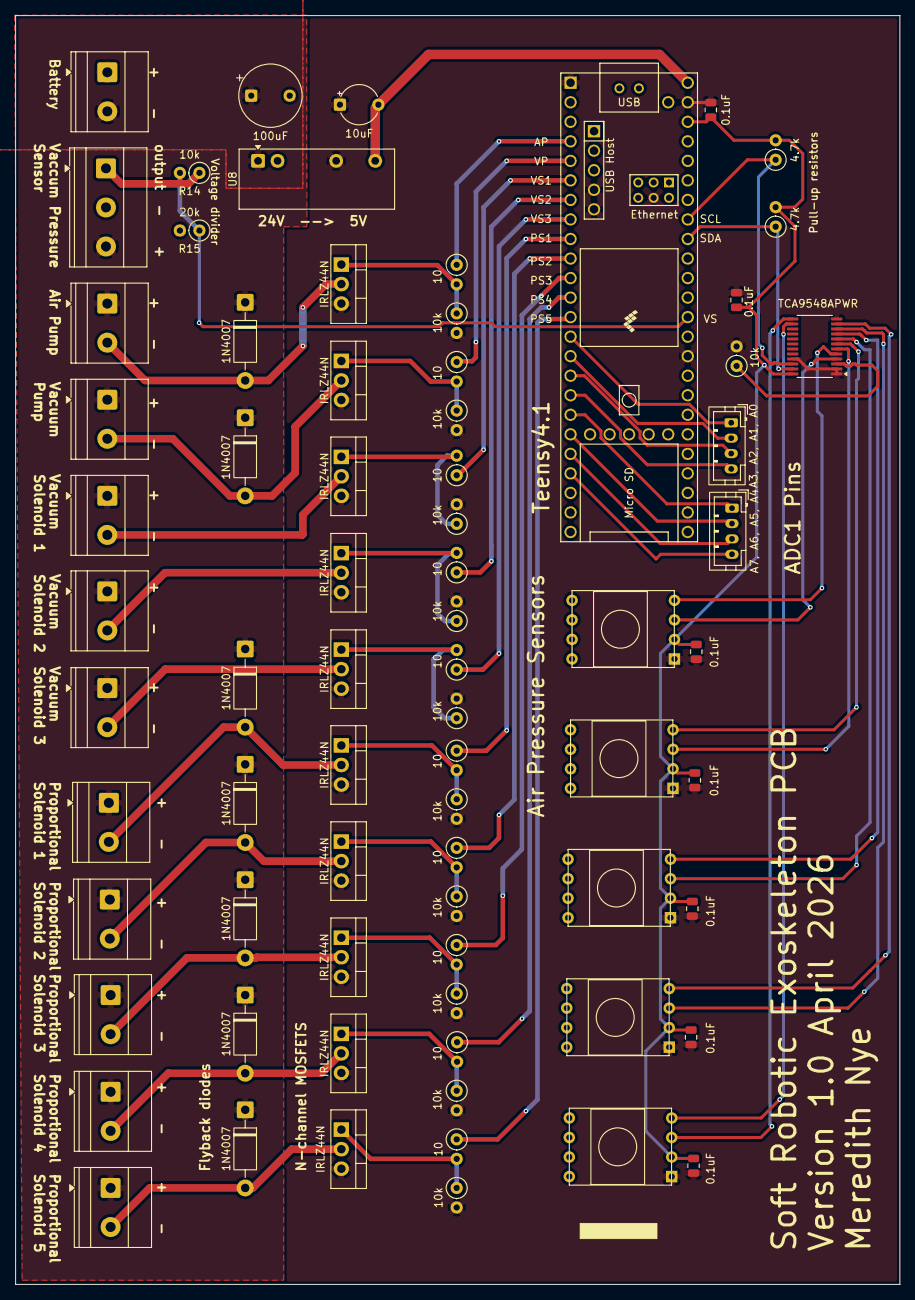
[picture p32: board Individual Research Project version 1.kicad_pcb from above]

Board: 4 copper layers, 115.0 x 165.0 mm, 73 parts (0 on the bottom side), 58 nets.

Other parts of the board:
A3, A2, A1, A0, A7, A6, A5, A4: Conn_01x04_Pin; JST_PH_B4B-PH-K_1x04_P2.00mm_Vertical

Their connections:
unnamed 15: A3, A2, A1, A0.1; also elsewhere on the board
unnamed 16: A3, A2, A1, A0.2; also elsewhere on the board
unnamed 17: A3, A2, A1, A0.3; also elsewhere on the board
unnamed 18: A3, A2, A1, A0.4; also elsewhere on the board
unnamed 19: A7, A6, A5, A4.1; also elsewhere on the board
unnamed 20: A7, A6, A5, A4.2; also elsewhere on the board
unnamed 21: A7, A6, A5, A4.3; also elsewhere on the board
unnamed 22: A7, A6, A5, A4.4; also elsewhere on the board

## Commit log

2026-08-12 Rename Full Finger Exoskeleton from Onshape.step to Manufacturing/Full Finger Exoskeleton from Onshape.step
    [Full Finger Exoskeleton from Onshape.step]
2026-08-12 Rename right half finger_male mold piece.stl to Manufacturing/right half finger_male mold piece.stl
    [right half finger_male mold piece.stl]
